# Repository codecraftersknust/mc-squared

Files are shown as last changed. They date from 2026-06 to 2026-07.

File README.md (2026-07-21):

#  Team mc-squared — WRO 2026 Future Engineers

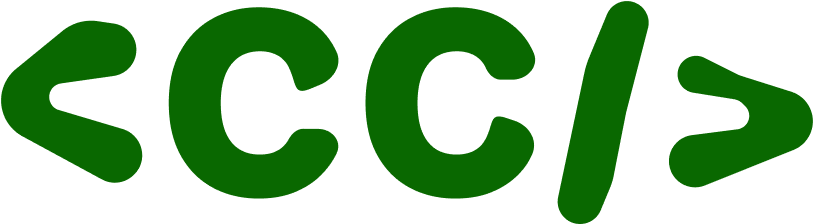
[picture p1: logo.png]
Team Logo

*Official codecraftersknust logo*

---

## Introduction

Welcome to the official repository of **mc-squared**, a passionate robotics team competing in the **2026 World Robot Olympiad (WRO) Future Engineers Challenge**.

Our mission is to design and build a reliable, fully autonomous vehicle capable of combining advanced computer vision with precise and intelligent driving. Through continuous iteration, innovation, and teamwork, we strive to create a seamless integration of robust hardware and intelligent software.

This repository documents our design process, technical decisions, and development journey throughout the competition. We hope our work provides valuable insights for fellow robotics enthusiasts, future WRO participants, and anyone interested in autonomous systems.

Feel free to explore our repository, learn from our approach, and reach out to us using the contact information provided below if you have any questions or would like to connect.

Thank you for visiting, and we hope our journey inspires yours!

---

## The Team

Our team consists of 3 members and a coach, we are mc-squared from Ghana.

> Members

- **Michael Awinneriba Nkema** from [Kwame Nkrumah University of Science and Technology](https://www.knust.edu.gh/)
   - nkemamichael1105@gmail.com
- **Caleb Alhassan** from [Kwame Nkrumah University of Science and Technology](https://www.knust.edu.gh/)
   - calebalhassan00@gmail.com
- **Claresta Gytha Quist** from [Kwame Nkrumah University of Science and Technology](https://www.knust.edu.gh/)
   - klaire.builds@gmail.com

> Coach

- **Dr Kingsford Sarkodie Obeng Kwakye** from [Kwame Nkrumah University of Science and Technology](https://www.knust.edu.gh/)
   - ksobengkwakye@knust.edu.gh

> Links to our socials:

- **YouTube**: https://www.youtube.com/@codecraftersknust
   - Link attached for our channel containing preparation videos and other content
---

##  Repository Structure

This repository contains all open-source engineering materials, code bases, and structural layouts required to fully reproduce our autonomous vehicle:

- `t-photos/` — Contains our official team portrait and our casual/behind-the-scenes engineering photo.
- `v-photos/` — Complete 6-sided orthographic photographic catalog of the vehicle (Front, Back, Left, Right, Top, Bottom) for technical inspection compliance.
- `video/` — Contains `video.md` enclosing the official YouTube demonstration link of our vehicle executing autonomous laps.
- `schemes/` — High-definition electromechanical schematic diagrams outlining pinouts, shared grounding, and logic-to-high-power isolation.
- `src/` — Production source code separated by processing layers (Python for high-level logic, C++ for real-time motor control).
- `models/` — Parametric 3D print `.STL` files for custom steering components, camera mounts level deck mounts.
- `other/` — Technical datasets, local calibration sheets, and secure headless connection guides (SSH over direct Ethernet link).

---

## Special Thanks
We are deeply grateful to the **Responsible AI Lab** at KNUST for their generous funding and equipment support that made this project possible. Our sincere appreciation also goes to the KNUST **College of Engineering Innovation Centre** for providing us with workspace and resources for our practice sessions. We'd like to thank the **Council for Scientific and Industrial Research - Institute for Scientific and Technological Information** for their invaluable guidance and support throughout this journey. Finally, we couldn't have done this without the patience and encouragement of our **friends and families**, who supported us through countless late nights and tolerated our robot taking over their spaces.

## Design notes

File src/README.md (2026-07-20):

# Control Software

This directory contains all control software developed by the team for the WRO Future Engineers competition vehicle. The software stack is split into **main** competition scripts and **other** utilities used during development and calibration.

---

## Main Scripts

### `launcher.py`
The primary entry point for the vehicle. Listens for button presses on **GPIO 16** and launches the appropriate competition script based on the number of clicks within a 2.5-second window:

| Presses | Script Launched |
|---|---|
| 1 | `round-1-left.py` — Round 1, left-wall follow |
| 2 | `round-1-right.py` — Round 1, right-wall follow |
| 3 | `round-2-left.py` — Round 2, left-wall follow + block avoidance |
| 4 | `round-2-right.py` — Round 2, right-wall follow + block avoidance |

### `round-1-left.py`
Round 1 script that follows the **left wall** using an ultrasonic sensor (GPIO 23/24). Applies a smooth PID controller (with derivative filtering and integral clamping) to hold the vehicle at 220 mm from the wall. Uses the **Pi Camera** to detect the orange starting line via HSV masking — every 4 detections counts as one lap, and the vehicle stops after completing 3 laps. Includes corner detection via distance spike (>1000 mm) with a 0.8 s cooldown to prevent re-triggering.

### `round-1-right.py`
Same structure as `round-1-left.py` but follows the **right wall** (GPIO 27/22). Used when the course direction is clockwise. Corner detection triggers a hard right turn (45°) instead of left, and the same lap counting and cooldown logic applies.

### `round-2-left.py`
Round 2 script built on `round-1-left.py` with added **colour block avoidance**. Uses the Pi Camera to detect red and green obstacles in a center ROI (Y: 40–90%, X: 15–85%). When a block's contour area exceeds the trigger threshold, the vehicle steers away for 1.8 seconds before resuming wall following:
- **Red block** → steer right (pass on left)
- **Green block** → steer left (pass on right)

Avoidance takes priority over corner turns, which take priority over normal wall following.

### `round-2-right.py`
Same as `round-2-left.py` but follows the **right wall**. Corner detection triggers a hard right turn and the avoidance steering directions remain the same.

### `motor-run/motor-run.ino`
Arduino firmware that receives `angle,speed\n` commands over UART and drives the **steering servo (D3)** and **ESC motor (D7)**. Angles are clamped to 45°–135° and ESC values to 1500–2000 µs. On startup the ESC is armed before the vehicle is ready to accept commands.

---

## Running the Main Scripts

```bash
# Start the launcher (select script via button presses)
python3 src/main/launcher.py

# Or run competition scripts directly:
python3 src/main/round-1-left.py   # Round 1 — left-wall follower
python3 src/main/round-1-right.py  # Round 1 — right-wall follower
python3 src/main/round-2-left.py   # Round 2 — left-wall + block avoidance
python3 src/main/round-2-right.py  # Round 2 — right-wall + block avoidance
```

> **Port note:** The Arduino uses `/dev/ttyUSB0` by default. Verify with `ls /dev/ttyUSB*` and update the `ARDUINO_PORT` constant at the top of each script if needed.

---

## Utility Scripts (`other/`)

| Script / Sketch | Purpose |
|---|---|
| `block_detector.py` | Live camera tool to tune and test block detection thresholds — displays bounding boxes and contour areas for red/green blocks |
| `cam-test.py` | Verifies the Pi Camera is detected and operational |
| `lidar-test.py` | Prints LiDAR device info, health status, and one sample scan |
| `lidar-reset.py` | Safely stops, idles, and disconnects the LiDAR after a crashed session |
| `plot_lidar.py` | Live polar plot of LiDAR scan data using matplotlib |
| `steering_test.py` | Interactive CLI tool to send manual servo angles to the Arduino over Serial |
| `arduino-files/angle-test/` | Arduino sketch — Serial-controlled servo angle tester |
| `arduino-files/calibrate/` | Arduino sketch — ESC calibration routine (max → min → neutral) |
| `arduino-files/esc-test/` | Arduino sketch — basic ESC run/stop cycle to verify wiring |
| `arduino-files/servo-test/` | Arduino sketch — auto-sweeps servo through 45°, 90°, 135° |

---

## Dependencies

```bash
pip install pyserial opencv-python numpy picamera2 RPi.GPIO
```

| Package | Purpose |
|---|---|
| `pyserial` | UART communication with the Arduino |
| `opencv-python` | Camera frame processing and colour detection |
| `numpy` | Array operations for image processing |
| `picamera2` | Raspberry Pi Camera interface |
| `RPi.GPIO` | Ultrasonic sensor and button GPIO control |

Arduino sketches use only the built-in `Servo.h` library — no extra installation needed.

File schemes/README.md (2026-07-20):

# Hardware Documentation and Setup Guide

## Overview

Our autonomous vehicle is built on a LaTrax Rally RC car chassis, modified with custom electronics and sensors for the WRO Future Engineers competition.

The system integrates:

- Raspberry Pi Camera Module
- HC-SR04 Ultrasonic Sensors
- Raspberry Pi 4B (high-level processing)
- Arduino Nano (low-level motor control)
- 11.1V LiPo battery with regulated power distribution

---

# Hardware Components

| Component | Specifications |
| --- | --- |
| Base Chassis | LaTrax Rally RC Car |
| Dimensions (Stock) | 380 × 185 mm |
| Modified Size | Meets WRO competition requirements (300 × 200 × 300 mm maximum) |
| Weight (Stock) | ~430 g |

## Raspberry Pi 4B (Main Computer)

| Specification | Value |
| --- | --- |
| RAM | 8 GB |
| Operating Voltage | 5V (USB-C) |
| Purpose | High-level computing, vision processing, navigation |

---

## Raspberry Pi Camera Module

| Specification | Value |
| --- | --- |
| Ribbon flex cable | 15 cm × 50 cm × 30 cm |
| Camera Dimensions | 25 mm × 24 mm × 9 mm |
| Power | 5V / 250 mA |
| Operating Voltage. | 5V DC |
| Purpose | Vision processing, navigation |

---

## HC-SR04 Ultrasonic Sensor

| Specification | Value |
| --- | --- |
| Scan Range | 2cm to 450 cm |
| High precision | 0.3 cm |
| Effectual Angle. | <15° |
| Working Voltage | 5V DC |
| Dimensions | 45 mm × 20 mm × 15 mm |
| Power | 5V / 15 mA |
| Purpose | Side wall detection and distance measurement |

---

## Electronic Speed Controller (ESC)

| Specification | Value |
| --- | --- |
| Model | CL9030 ESC |
| Battery Support | 2S–3S LiPo (7.4V–11.1V) |
| Continuous Current | 90 A |

---

## Steering Servo

| Specification | Value |
| --- | --- |
| Model | Stock LaTrax Steering Servo |

---

## Power System

| Component | Specification |
| --- | --- |
| Main Battery | 11.1V 2200mAh 3S LiPo |
| Voltage Regulation | DC-DC Buck Converter (11.1V → 5V) |

---

## Microcontroller

| Specification | Value |
| --- | --- |
| Board | Arduino Nano |
| Microcontroller | ATmega328P |
| Operating Voltage | 5V |
| Purpose | Motor and steering control |

---

# Assembly

The stock LaTrax Rally chassis was modified to comply with the WRO Future Engineers regulations and to accommodate all sensors and electronics.

## 1. Size Reduction

- Trimmed body panels to fit within the competition dimensions.
- Final dimensions comply with the 300 × 200 × 300 mm size limit.

---

## 2. Electronics Mounting

- Designed and 3D-printed custom mounting plates for:
  - Raspberry Pi 4B
  - Raspberry Pi Camera Module
  - HC-SR04 Ultrasonic Sensor
- Implemented cable management using:
  - Braided cable sleeves
  - Zip ties

---

## 3. Sensor Integration

### Raspberry Pi Camera Module

- Mounted at the front of the vehicle.
- Provides an optimal forward view for:
  - Lap count
  - Obstacle detection

### HC-SR04 Ultrasonic Sensor

- Mounted on the lower deck.
- Used for:
  - Left wall detection
  - Right wall detection
  - Vehicle localization

Sensors were positioned to maximize wall detection strategy.

---

## 4. Weight Distribution

To improve stability and handling:

- Battery mounted as low as possible.
- Left/right weight distribution carefully balanced.
- Center of gravity verified after assembly.

---

# Component Layout

### Assembled Top Layer

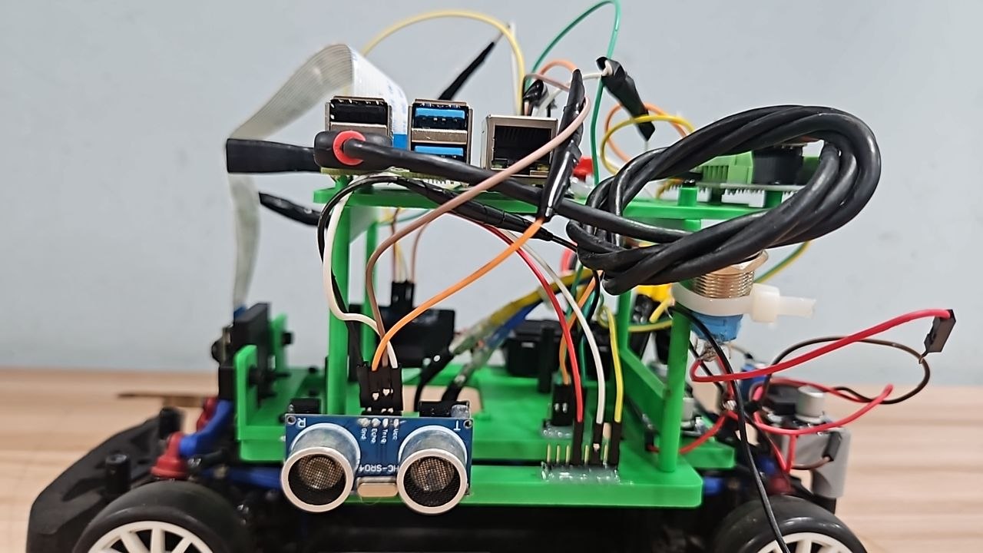
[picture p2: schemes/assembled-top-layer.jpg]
Assembled top layer diagram


---

### Bottom Layer Assembly

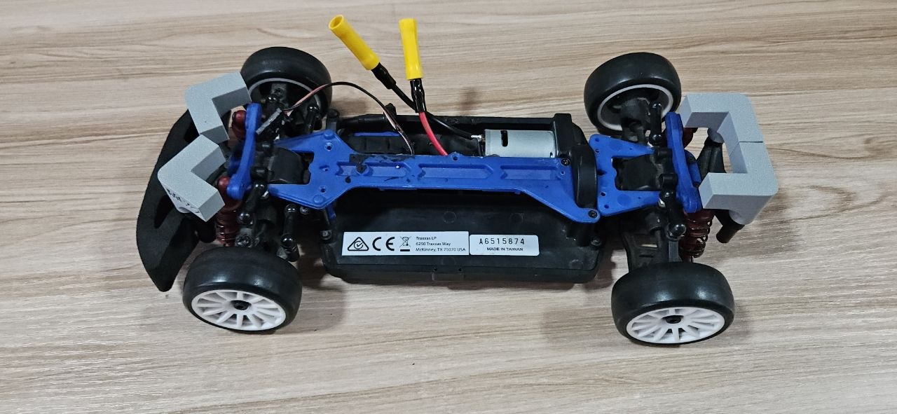
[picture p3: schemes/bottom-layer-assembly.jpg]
Bottom layer assembly diagram


---

# Power Distribution

The power system distributes energy from the 3S LiPo battery to all onboard electronics through a regulated power network.

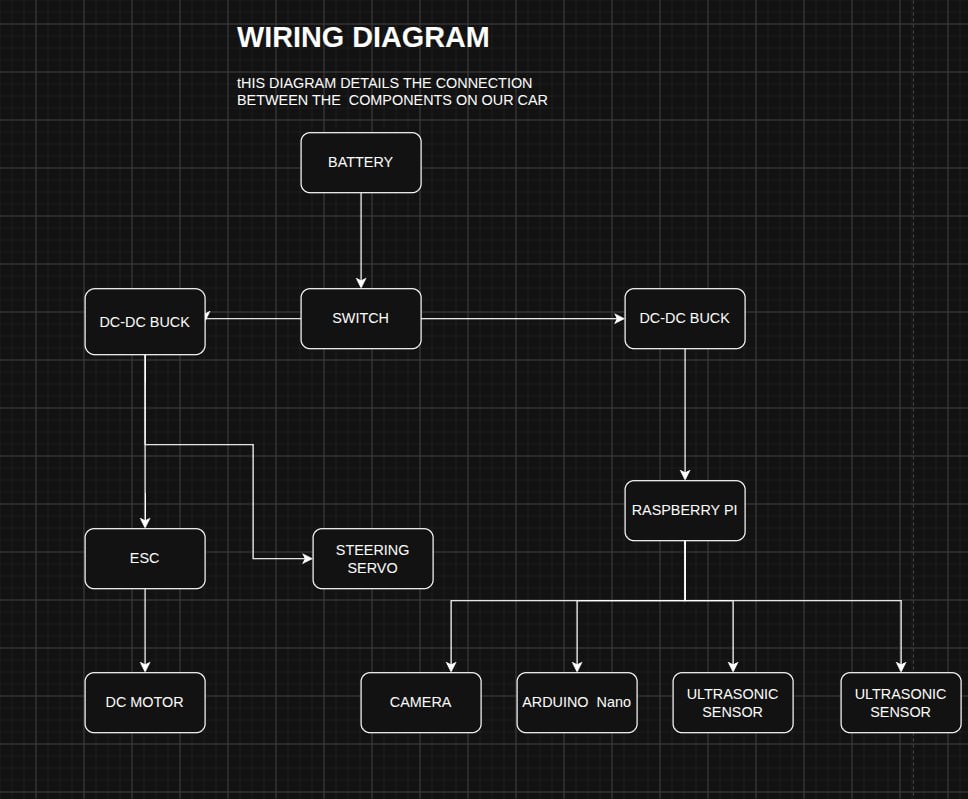
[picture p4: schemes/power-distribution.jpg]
Power Distribution


---

# Signal Wiring

The Raspberry Pi communicates with sensors while the Arduino controls the steering servo and ESC.

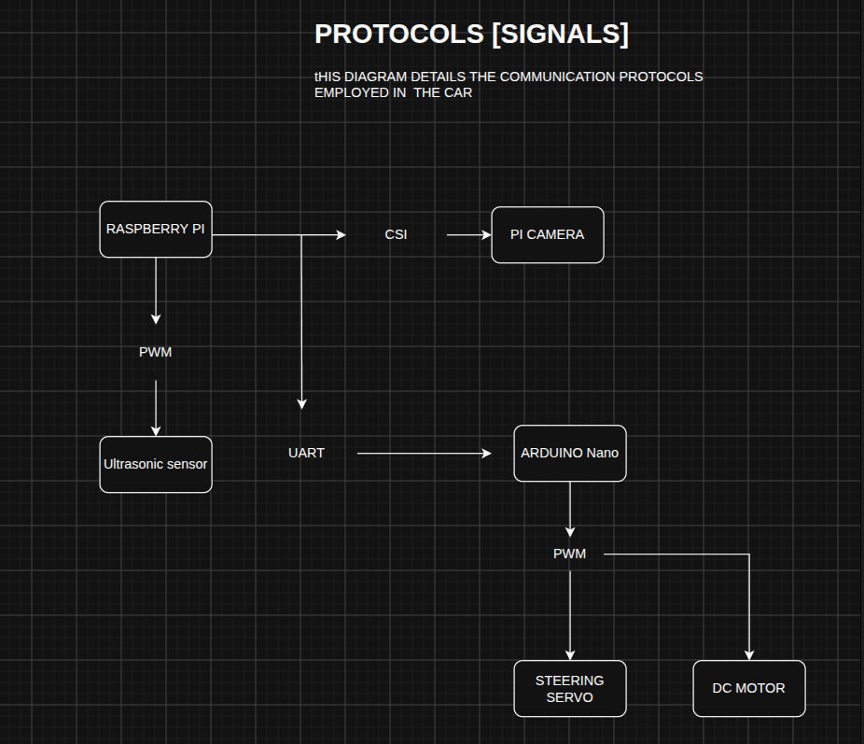
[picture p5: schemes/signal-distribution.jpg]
Signal Distribution


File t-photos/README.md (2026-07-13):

# Team Photos

This directory contains 2 photos of the team.
The Team name mc^2 is derived from the team member's initials. First in the team is Michael, the programming lead of the team, second comes Caleb, the construction lead of the team and finally the third member is Claresta, the design lead of the team.

---

### Official Photo
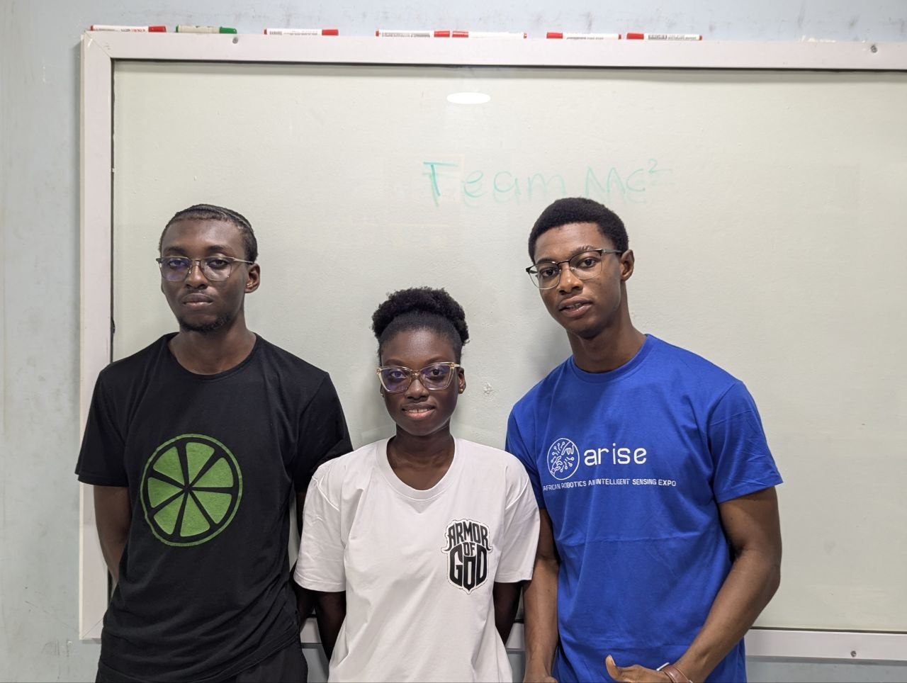
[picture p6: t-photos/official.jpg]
Official team photo


---

### Funny Photo
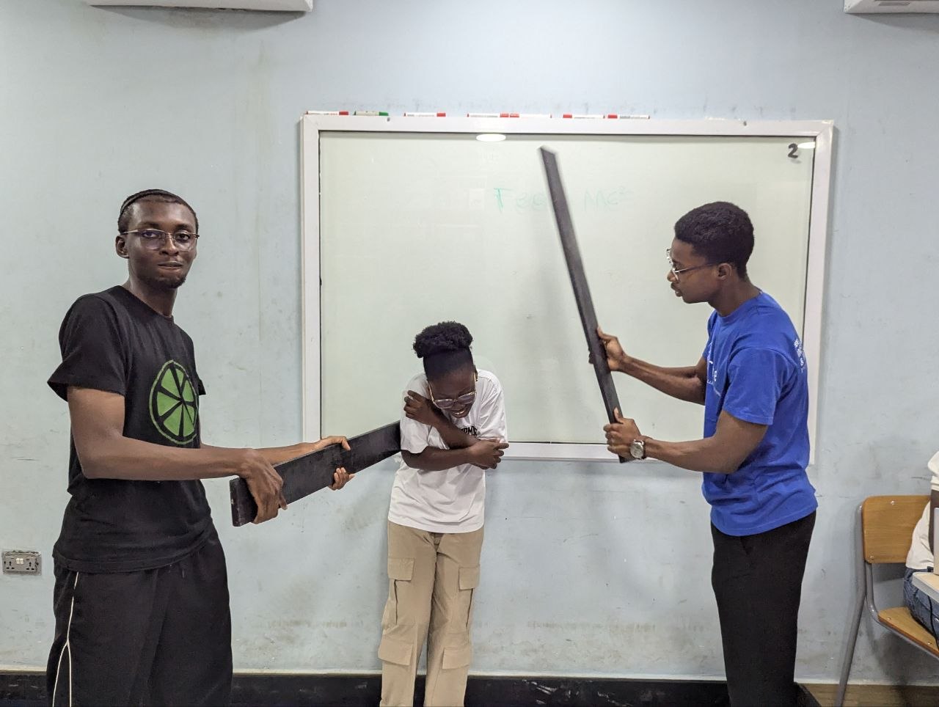
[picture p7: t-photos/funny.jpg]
Funny team photo


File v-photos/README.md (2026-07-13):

# Vehicle Photos

This directory contains 6 photos of the vehicle — from every side, from top and bottom.

---

### Top View
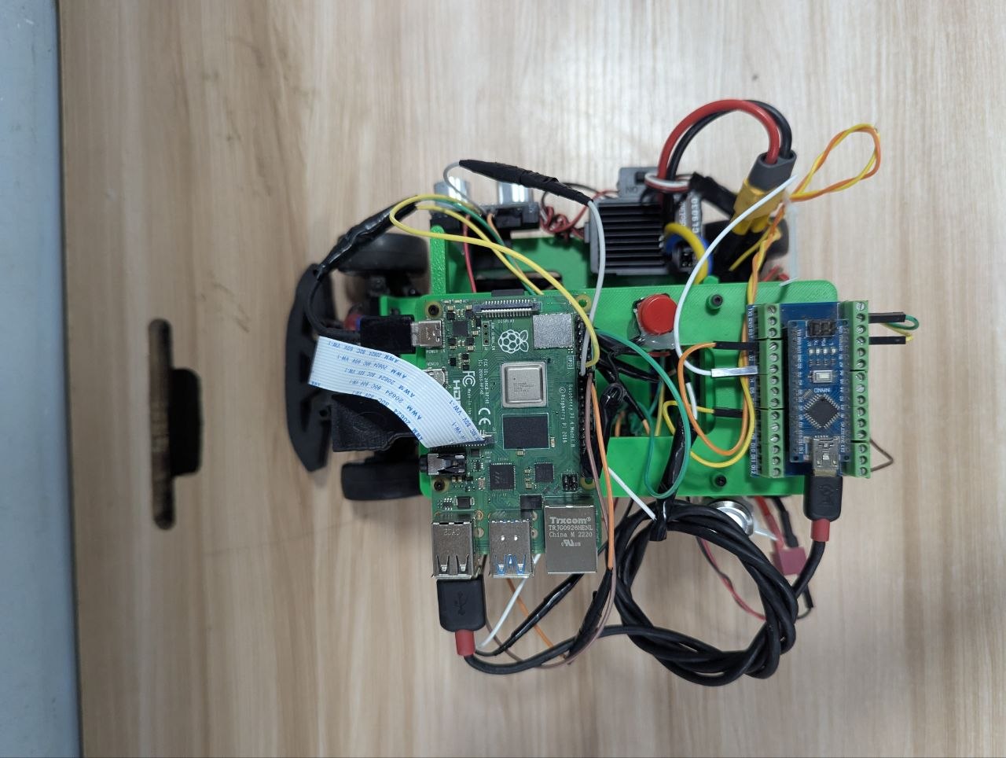
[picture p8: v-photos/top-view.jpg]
Top view of the robot


---

### Bottom View
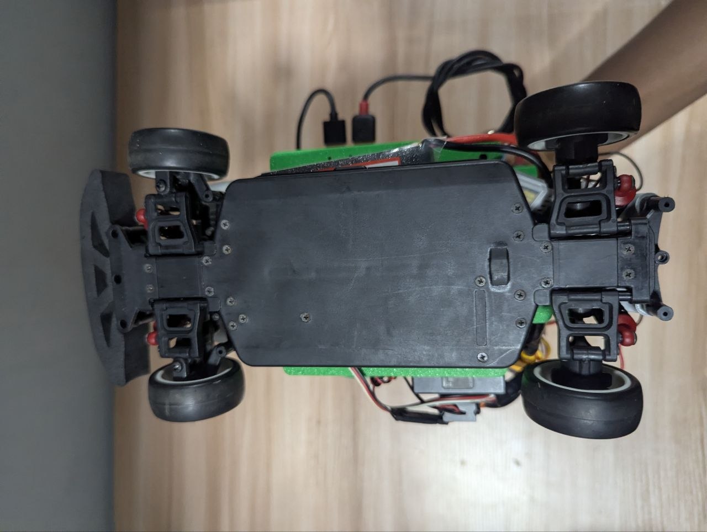
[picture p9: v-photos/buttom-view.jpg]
Bottom view of the robot


---

### Front View
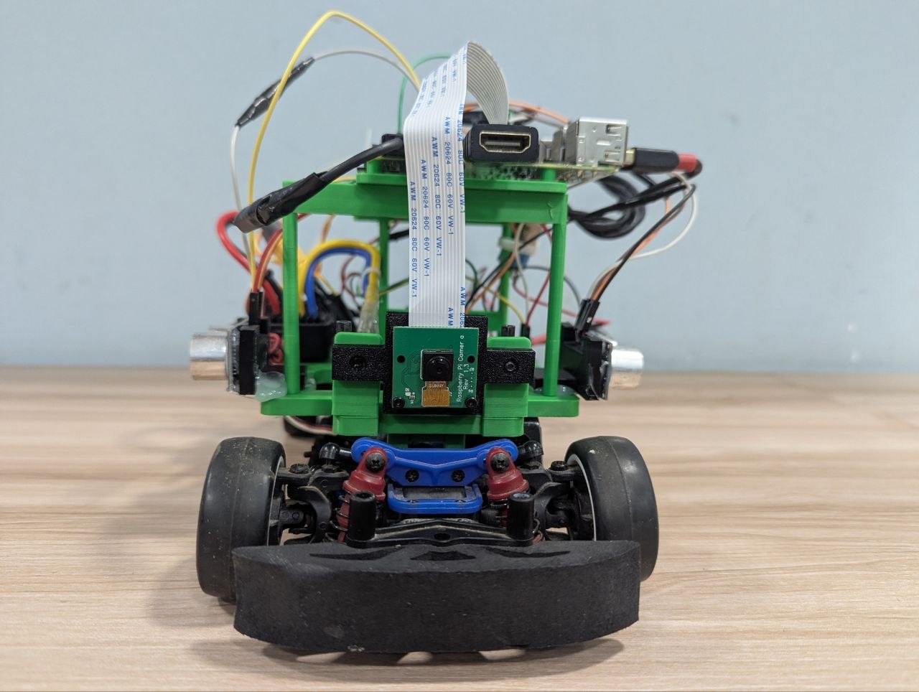
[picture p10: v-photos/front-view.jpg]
Front view of the robot


---

### Back View
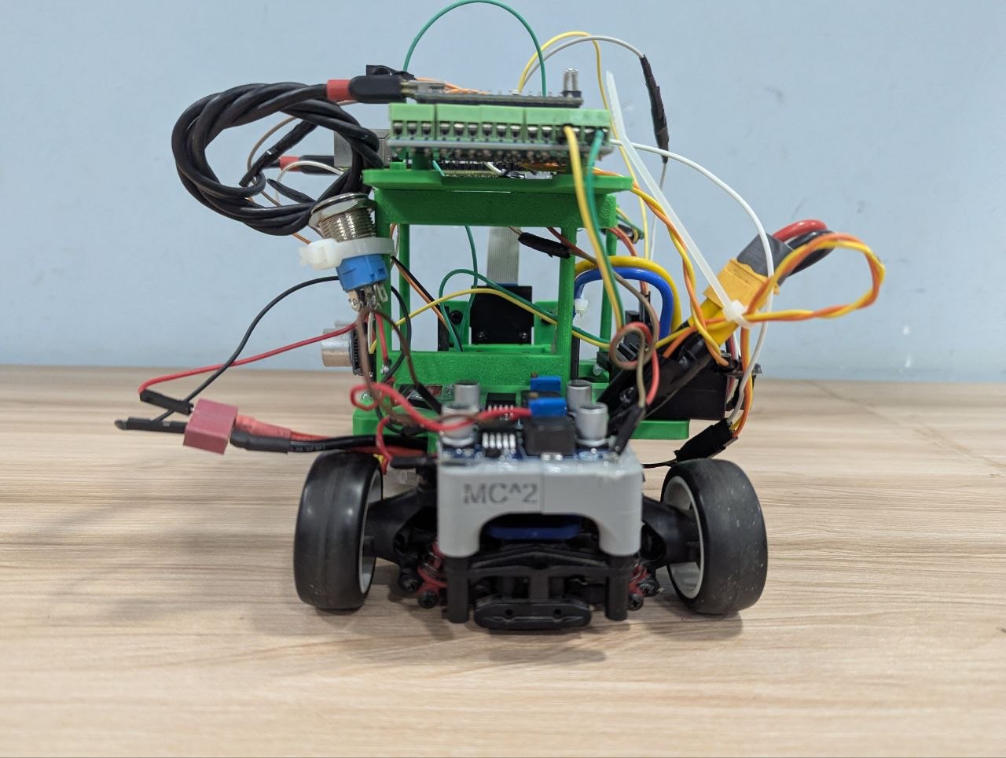
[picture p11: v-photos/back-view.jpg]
Back view of the robot


---

### Left Side View
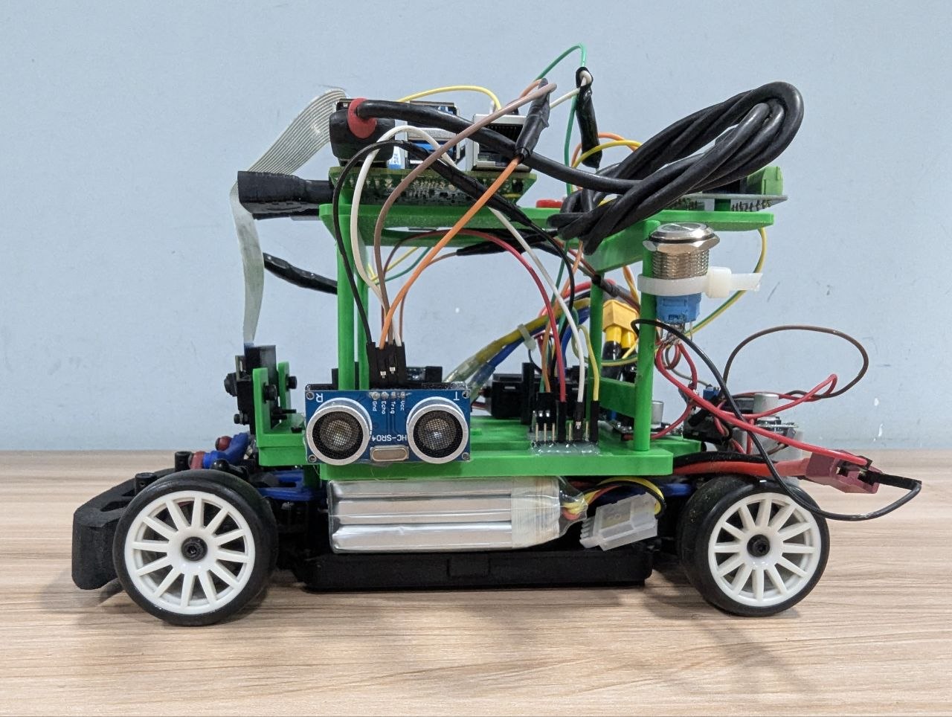
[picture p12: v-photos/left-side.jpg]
Left side view of the robot


---

### Right Side View
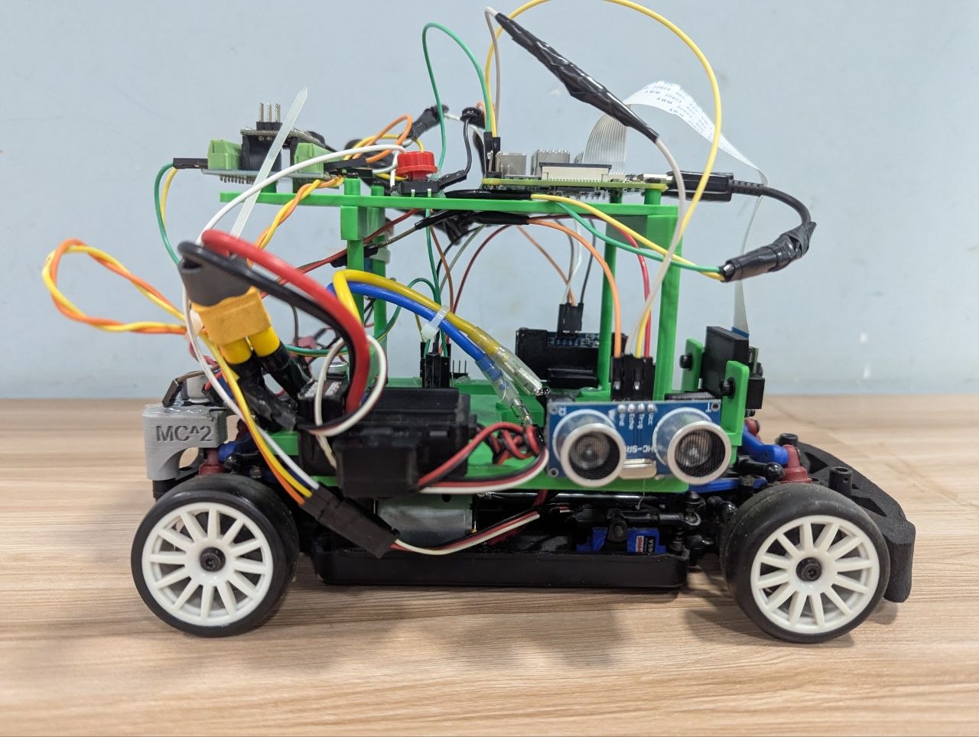
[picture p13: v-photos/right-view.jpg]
Right side view of the robot


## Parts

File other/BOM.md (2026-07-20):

# Bill of Materials(BOM)

| Component | Quantity | Description | Cost (USD) | URL |
| --- | --- | --- | --- | --- |
| LaTrax Rally RC Car | 1 | Chassis and mechanical structure | $119.95 | [Buy from Traxxas](https://traxxas.com/75054-5-118-latrax-rally) |
| Raspberry pi 4b 8gb | 1 | Main processor for navigation and control | $180.00 | [Buy from Amazon](https://www.amazon.com/Raspberry-Pi-Computer-Suitable-Workstation/dp/B0899VXM8F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) |
| Raspberry pi camera 1.3 module | 1 | Camera module for vision-avoidance and lap counting | $25.00 | [Buy from Raspberry Pi Store](https://www.raspberrypi.com/products/camera-module-3/) |
| Ultrasonic Sensors (HC-SR04) | 2 | Distance measurement for wall following | $10.00 | [Buy from Amazon](hhttps://www.amazon.com/HC-SR04-ultrasonic-sensor-Electronics/s?k=HC-SR04+ultrasonic+sensor&rh=n%3A172282) |
| Arduino Nano | 1 | Microcontroller for motor control | $18.00 | [Buy from Arduino Store](https://store.arduino.cc/products/nano-every?queryID=undefined) |
| CL9030 ESC | 1 | For controlling driving motor | $29.99 | [Buy from Amazon](https://www.amazon.com/Radiolink-CL9030-Waterproof-Electric-Controller/dp/B0DYJ8NKBP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) |
| 11.1V 2200mAh 3S LiPo | 1 | Power supply for the system | $49.99 | [Buy from Zeee](https://zeeebattery.com/collections/zeee-3s-lipo-battery/products/zeee-3s-2200mah-lipo-battery-11-1v-50c-xt60-plug) |
| Step-Down Voltage Regulator  | 2 | Converts 11.1V to required voltage levels for the servo motor, and raspberry pi 4b | $7.99 | [Buy from Amazon](https://www.amazon.com/Seloky-Converter-Adjustable-Electronic-Stabilizer/dp/B0DBVYP91F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) |
| 3D printed parts | 7 | | | [STL File](https://github.com/codecraftersknust/mc-squared/tree/main/models) |
| Illuminated Halo Ring Switch | 2 | | $8.98 | [Buy from Amazon](https://www.amazon.com/API-ELE-warranty-Latching-Button-Metal1NO1NC/dp/B07932GYNH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) |
| Screw Pack (M2, M3) | 1 | | $99.00 | [Buy from Amazon](https://www.amazon.com/gp/product/B01FXGHO2M/?th=1) |
| Micro SD Card | 1 | Must be at least 32GB | $44.00 | [Buy from Amazon](https://www.amazon.com/Samsung-MicroSDXC-Adapter-MB-ME64GA-AM/dp/B06XWZWYVP/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) |
| Jumper Wire Pack | 1 | >15cm | $6.98 | [Buy from Amazon](https://www.amazon.com/EDGELEC-Breadboard-Optional-Assorted-Multicolored/dp/B07GD2BWPY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) |

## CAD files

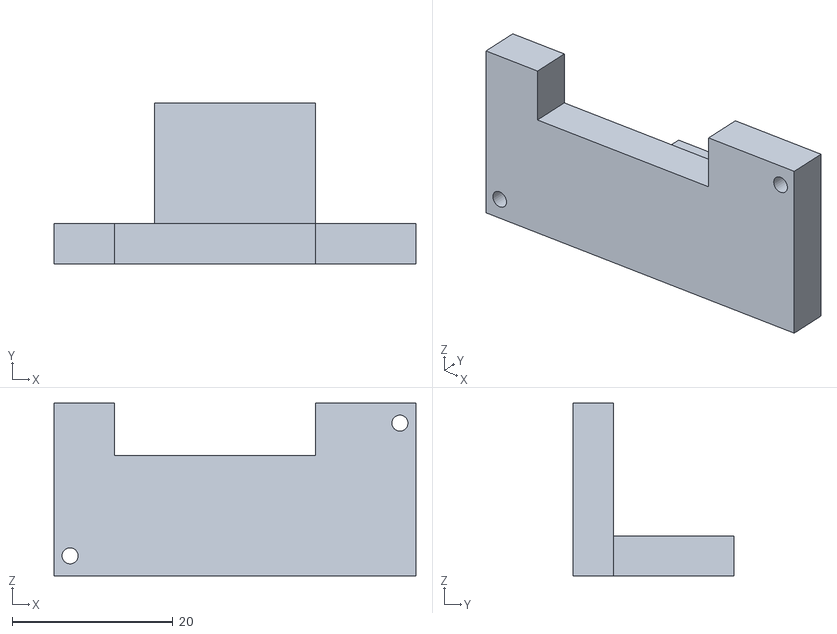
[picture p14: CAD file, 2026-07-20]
models/ultrasonic sensor mount.stl
45.0 x 20.0 x 21.5

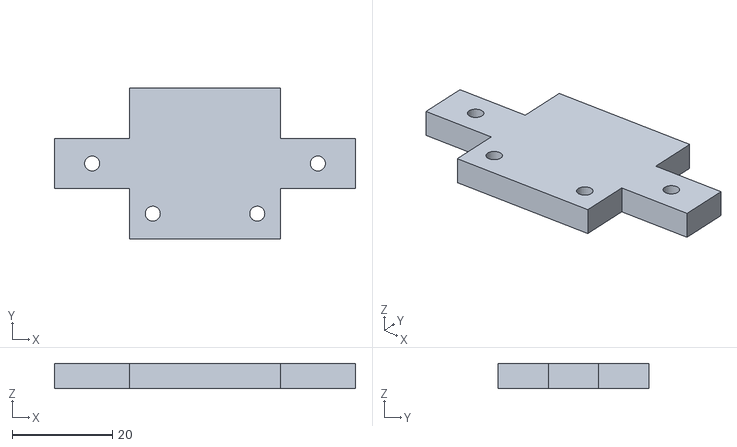
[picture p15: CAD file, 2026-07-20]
models/PI CAMERA MOUNT.stl
60.0 x 30.0 x 5.00

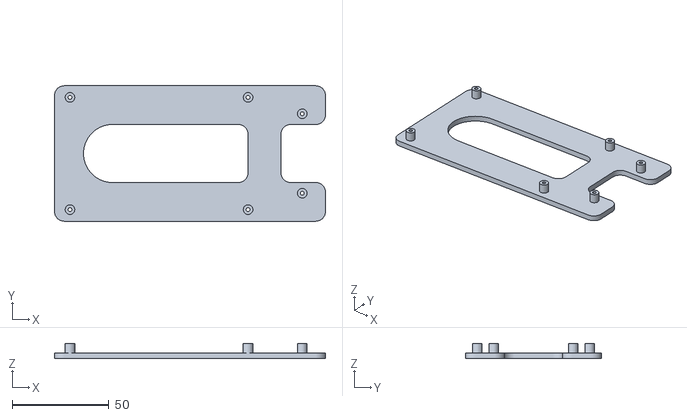
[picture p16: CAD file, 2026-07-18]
models/top-plate v4.stl
140.0 x 70.0 x 8.00

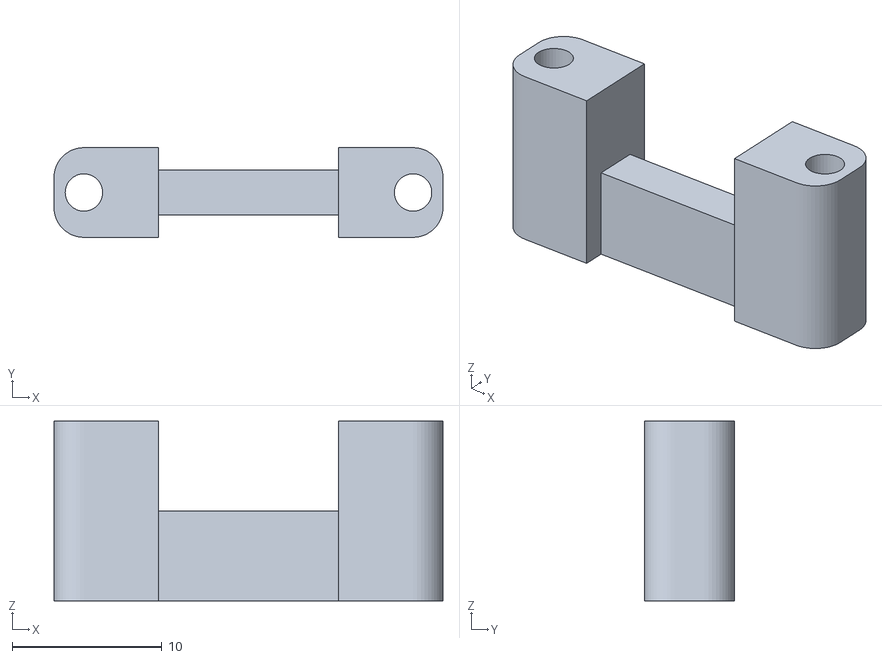
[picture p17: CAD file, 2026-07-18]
models/standoff-v1.stl
26.0 x 6.00 x 12.0

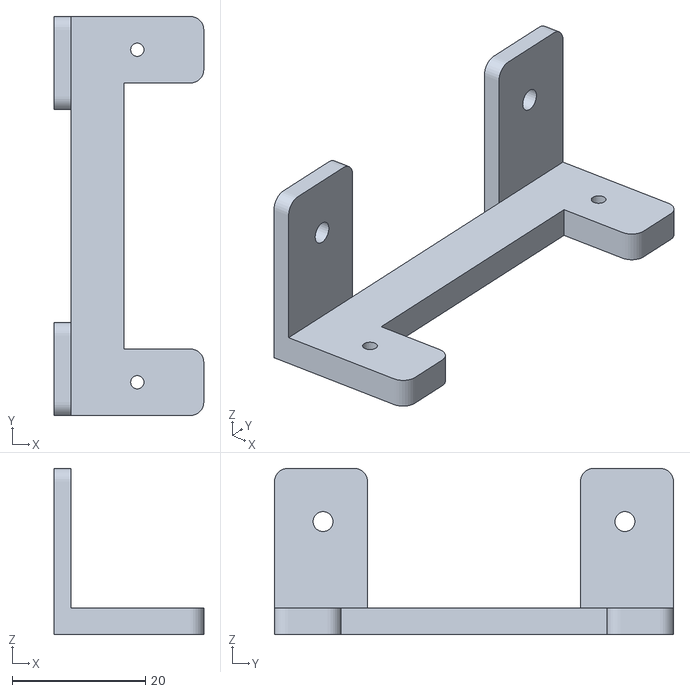
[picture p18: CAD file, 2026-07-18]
models/camera-stand-v4.stl
22.5 x 60.0 x 25.0

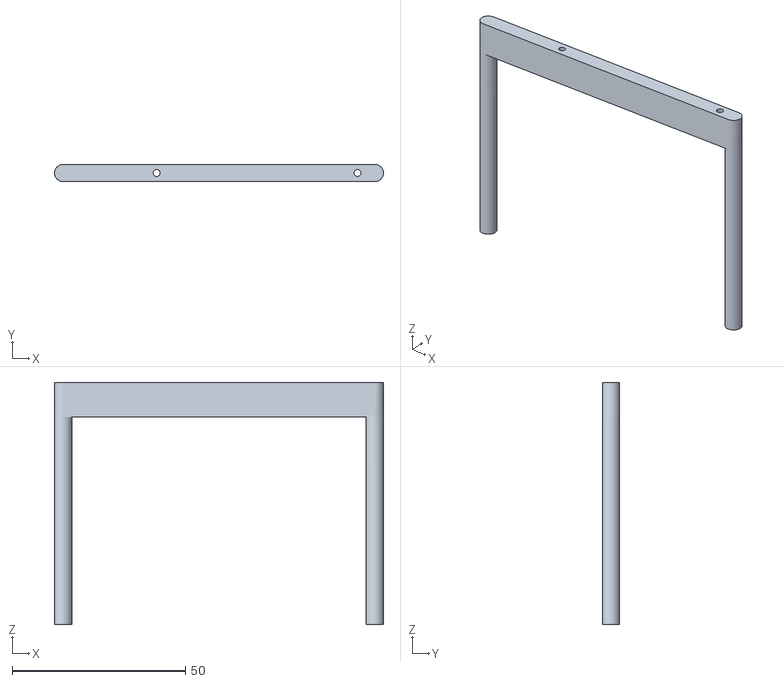
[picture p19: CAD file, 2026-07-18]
models/jetson-support-front v2.stl
95.0 x 5.00 x 70.0

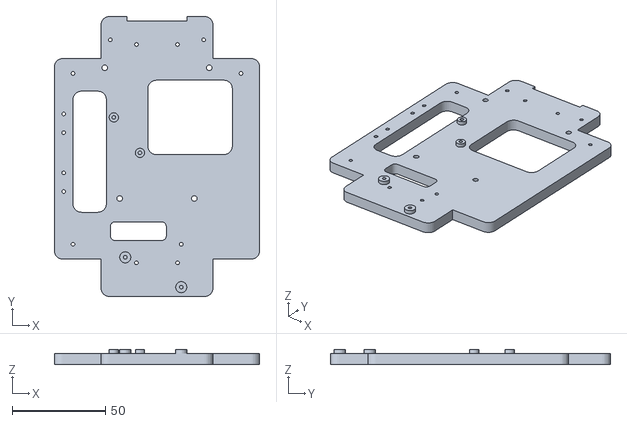
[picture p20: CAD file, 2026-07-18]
models/base v5.stl
110.0 x 150.0 x 8.00

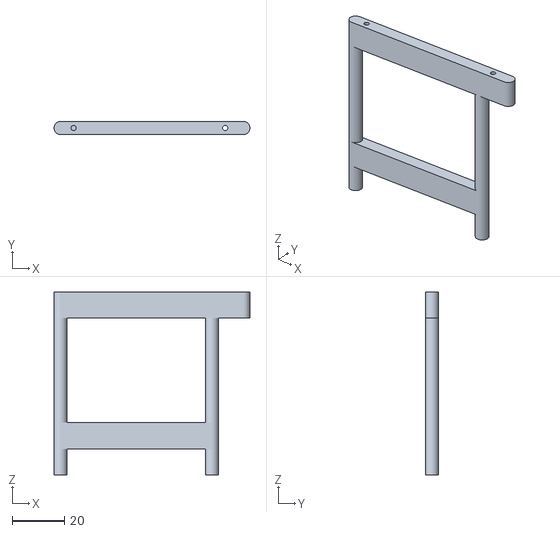
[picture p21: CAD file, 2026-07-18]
models/jetson-support-rear v5.stl
75.0 x 5.00 x 70.0

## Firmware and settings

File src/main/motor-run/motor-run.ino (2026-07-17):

#include <Servo.h>

Servo steeringServo;
Servo escMotor;

const int SERVO_PIN = 3;
const int ESC_PIN = 7;

// Limits
const int STEERING_MIN = 45;
const int STEERING_MAX = 135;
const int STEERING_CENTER = 90;

const int ESC_MIN = 1500;   // stop
const int ESC_MAX = 2000;

String inputString = "";
bool stringComplete = false;

void setup() {
  Serial.begin(115200);

  steeringServo.attach(SERVO_PIN);
  escMotor.attach(ESC_PIN);

  // Center steering
  steeringServo.write(STEERING_CENTER);

  // Arm ESC (IMPORTANT)
  escMotor.writeMicroseconds(1000);
  delay(100);

  // Start motor slowly (optional safety)
  escMotor.writeMicroseconds(1600);

  inputString.reserve(50);

  Serial.println("Ready");
}

void loop() {

  if (stringComplete) {

    int commaIndex = inputString.indexOf(',');

    if (commaIndex > 0) {

      String angleStr = inputString.substring(0, commaIndex);
      String speedStr = inputString.substring(commaIndex + 1);

      int angle = angleStr.toInt();
      int speed = speedStr.toInt();

      // Clamp values for safety
      angle = constrain(angle, STEERING_MIN, STEERING_MAX);
      speed = constrain(speed, ESC_MIN, ESC_MAX);

      // Apply to hardware
      steeringServo.write(angle);
      escMotor.writeMicroseconds(speed);

      Serial.print("Angle: ");
      Serial.print(angle);
      Serial.print(" Speed: ");
      Serial.println(speed);
    }

    inputString = "";
    stringComplete = false;
  }
}

// Serial event handler
void serialEvent() {
  while (Serial.available()) {
    char inChar = (char)Serial.read();

    if (inChar == '\n') {
      stringComplete = true;
    } else {
      inputString += inChar;
    }
  }
}

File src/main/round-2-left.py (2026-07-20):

import time
import serial
import cv2
import numpy as np
from picamera2 import Picamera2
import RPi.GPIO as GPIO

# ---------- Hardware Configuration ----------
ARDUINO_PORT = '/dev/ttyUSB0'
BAUD_RATE = 115200

# Left Ultrasonic Pins
LEFT_TRIG = 23
LEFT_ECHO = 24

# Setpoints & Thresholds
TARGET_DIST_MM = 220        # Target distance from wall (22cm)
CORNER_SPIKE_THRESH = 1000  # Distance spike (mm) triggering corner turn
TURN_DURATION = 0.20        # Seconds to hold hard turn during corner
TURN_COOLDOWN = 0.80        # Lockout window (seconds) to prevent re-trigger loops

# Obstacle Avoidance Parameters
AVOID_DURATION = 1.80       # Seconds to hold dodge steering maneuver
AVOID_STEER_LEFT = 45       # Steer Left for Green Block (Pass on Right)
AVOID_STEER_RIGHT = 135     # Steer Right for Red Block (Pass on Left)

# Smoother PID Gains
Kp = 0.25
Ki = 0.002
Kd = 0.10
dt = 0.08

# Steering Limits
STEERING_MIN = 45           # Full Right Turn
STEERING_CENTER = 90
STEERING_MAX = 135          # Full Left Turn

# ESC Values
BASE_THROTTLE = 1665
STOP_THROTTLE = 1500

# Vision Config
# 1. Lap Counter (Orange)
LOWER_ORANGE = np.array([5, 120, 120])
UPPER_ORANGE = np.array([22, 255, 255])
ORANGE_PIXEL_THRESHOLD = 1200

# 2. Obstacles (Red & Green)
LOWER_RED_1 = np.array([0, 120, 70])
UPPER_RED_1 = np.array([10, 255, 255])
LOWER_RED_2 = np.array([165, 120, 70])
UPPER_RED_2 = np.array([180, 255, 255])

LOWER_GREEN = np.array([35, 80, 80])
UPPER_GREEN = np.array([85, 255, 255])

BLOCK_TRIGGER_THRESHOLD = 3000  # Contour pixel area required to trigger dodge

# ---------- Setup ----------
GPIO.setmode(GPIO.BCM)
GPIO.setup(LEFT_TRIG, GPIO.OUT)
GPIO.setup(LEFT_ECHO, GPIO.IN)
GPIO.output(LEFT_TRIG, False)

print("Connecting to Arduino & Camera...")
ser = serial.Serial(ARDUINO_PORT, BAUD_RATE, timeout=1)
time.sleep(2)

picam = Picamera2()
picam.preview_configuration.main.size = (640, 480)
picam.preview_configuration.main.format = "RGB888"
picam.preview_configuration.align()
picam.configure("preview")
picam.start()
time.sleep(1.0)

# ---------- Robot State Variables ----------
prev_error = 0
integral = 0
filtered_derivative = 0

orange_line_count = 0
line_detected_flag = False

# Corner Turn State
is_turning = False
turn_start_time = 0
last_turn_end_time = 0

# Obstacle Avoidance State
avoidance_mode = False
avoidance_start_time = 0
override_steering = STEERING_CENTER
avoidance_label = ""

def send_to_arduino(throttle, steer):
    ser.write(f"{int(steer)},{int(throttle)}\n".encode())

def get_left_distance():
    """Reads distance from left sensor. Returns None on timeout/wall loss."""
    try:
        GPIO.output(LEFT_TRIG, True)
        time.sleep(0.00001)
        GPIO.output(LEFT_TRIG, False)
        
        pulse_start = time.time()
        timeout = time.time()
        
        while GPIO.input(LEFT_ECHO) == 0:
            pulse_start = time.time()
            if pulse_start - timeout > 0.025:
                return None
                
        pulse_end = time.time()
        while GPIO.input(LEFT_ECHO) == 1:
            pulse_end = time.time()
            if pulse_end - pulse_start > 0.025:
                return None
                
        dist = ((pulse_end - pulse_start) * 343000) / 2
        return dist if 20 <= dist <= 2500 else None
    except:
        return None

def smooth_pid(error, prev_error, integral, prev_derivative, kp, ki, kd, dt):
    raw_derivative = (error - prev_error) / dt
    derivative = (0.3 * raw_derivative) + (0.7 * prev_derivative)
    
    integral += error * dt
    integral = max(min(integral, 100), -100)
    
    output = (kp * error) + (ki * integral) + (kd * derivative)
    return output, integral, derivative

# ---------- Main Loop ----------
try:
    print("\n==================================================")
    print("🚀 MC-SQUARED: ROUND 2 LEFT INNER FOLLOW + AVOIDANCE")
    print("==================================================\n")
    
    while True:
        current_time = time.time()

        # --- 1. PRIORITY 1: OBSTACLE AVOIDANCE TIMER OVERRIDE ---
        if avoidance_mode:
            if current_time - avoidance_start_time < AVOID_DURATION:
                send_to_arduino(BASE_THROTTLE, override_steering)
                print(f"🛑 DODGING {avoidance_label} ({current_time - avoidance_start_time:.2f}s)", end="\r")
                time.sleep(dt)
                continue
            else:
                print(f"\n✅ {avoidance_label} Cleared! Re-acquiring wall...")
                avoidance_mode = False
                # Hard reset PID and cooldown memory upon completing maneuver
                integral = 0
                prev_error = 0
                filtered_derivative = 0
                last_turn_end_time = current_time

        # --- 2. PRIORITY 2: CORNER TURN OVERRIDE ---
        if is_turning:
            if current_time - turn_start_time < TURN_DURATION:
                send_to_arduino(BASE_THROTTLE, STEERING_MAX)
                print(f"🌀 EXECUTING CORNER TURN ({current_time - turn_start_time:.2f}s)", end="\r")
                time.sleep(dt)
                continue
            else:
                print("\n✅ Turn complete! Locking out re-triggers for 0.8s...")
                is_turning = False
                last_turn_end_time = current_time
                integral = 0
                prev_error = 0
                filtered_derivative = 0

        # --- 3. VISION PROCESSING (Camera Lap Counting & Block Detection) ---
        try:
            frame_rgb = picam.capture_array()
            frame_rotated = cv2.rotate(frame_rgb, cv2.ROTATE_180)
            hsv = cv2.cvtColor(frame_rotated, cv2.COLOR_RGB2HSV)
            h, w, _ = hsv.shape

            # A. Lap Line Detection (Bottom 30%)
            roi_lap = hsv[int(h * 0.70):h, 0:w]
            mask_orange = cv2.inRange(roi_lap, LOWER_ORANGE, UPPER_ORANGE)
            orange_pixels = cv2.countNonZero(mask_orange)

            if orange_pixels > ORANGE_PIXEL_THRESHOLD:
                if not line_detected_flag:
                    orange_line_count += 1
                    line_detected_flag = True
                    current_laps = orange_line_count // 4
                    print(f"\n🍊 LAP LINE DETECTED! Total: {orange_line_count}/12 | Laps: {current_laps}/3")
            else:
                line_detected_flag = False

            if orange_line_count >= 12:
                print("\n🏆 ROUND 2 COMPLETE: 3 Laps Finished Successfully!")
                break

            # B. Obstacle Detection (Center Window: Y 40-90%, X 15-85%)
            roi_obs = hsv[int(h * 0.40):int(h * 0.90), int(w * 0.15):int(w * 0.85)]
            
            mask_red = cv2.bitwise_or(
                cv2.inRange(roi_obs, LOWER_RED_1, UPPER_RED_1),
                cv2.inRange(roi_obs, LOWER_RED_2, UPPER_RED_2)
            )
            mask_green = cv2.inRange(roi_obs, LOWER_GREEN, UPPER_GREEN)
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

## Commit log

2026-06-17 Bill of materials
2026-07-13 schemes, models and photos added
    [Level 0 deck.stl, base pin.stl, support pins.stl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]
2026-07-18 official first draft of documentation
    [Level 0 deck.stl, base pin.stl, base v5.stl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]
2026-07-20 Replaced Intel RealSense with Raspberry Pi Camera Module
    Updated the README to reflect the integration of the Raspberry Pi Camera Module instead of the Intel RealSense D435i for power optimisation. Added specifications for the new camera module and adjusted sections related to electronics mounting and sensor integration.
2026-07-20 2nd documentation draft
    [PI CAMERA MOUNT.stl, ultrasonic sensor mount.stl]
